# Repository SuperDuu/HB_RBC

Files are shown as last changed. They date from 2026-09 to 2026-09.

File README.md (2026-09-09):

# HB_RBC — H-Bridge DC Motor Driver (Robocon DKH 2026)

**HB_RBC** là mạch điều khiển động cơ DC (Full H-Bridge Driver) công suất cao được thiết kế phục vụ cho đội tuyển **Robocon DKH 2026**. 

Mạch hướng tới sự nhỏ gọn, độ tin cậy cao trong thi đấu thực tế, tích hợp sẵn vi điều khiển trung tâm, mạch lái cổng chống trùng dẫn, cổng phản hồi encoder vòng kín và giao tiếp mạng bus RS-485.

---

## 🚀 Tính năng & Cấu hình chính

- **Vi điều khiển trung tâm**: STM32G030F6Px (ARM Cortex-M0+ @ 64MHz) điều khiển băm xung PWM và xử lý thuật toán vòng kín.
- **Tầng công suất Cầu H**: 
  - 4x N-MOSFET **BSC040N10NS5** ($100\text{V}$, $4.0\text{ m}\Omega$, gói TDSON-8) trở kháng siêu thấp, tỏa nhiệt ít khi chạy tải nặng.
  - Diode xả tự do Schottky (SS310) bảo vệ chống xung ngược cảm ứng từ động cơ.
- **Mạch lái cổng (Gate Driver)**: 
  - 2x IC lái nửa cầu **IR2184** tích hợp sẵn deadtime phần cứng $500\text{ns}$ chống chập nguồn (shoot-through).
  - Tích hợp đường ngắt khẩn cấp phần cứng (`/S`), cho phép khóa cầu H ngay lập tức khi có sự cố.
- **Nguồn cấp**: 
  - Điện áp danh định: $12\text{V} \sim 24\text{V}$ DC (bảo vệ quá dòng qua cầu chì đầu vào).
  - Hạ áp 3 tầng riêng biệt: $24\text{V} \to 15\text{V}$ (Lái Gate) $\to 5\text{V}$ $\to 3.3\text{V}$ (Logic & MCU).
- **Giao tiếp & Cảm biến**:
  - **RS-485 (MAX3485)**: Giao tiếp vi sai chống nhiễu, tích hợp sẵn trở tải $120\Omega$ và mạch phân cực bus.
  - **Encoder AB**: Cổng nhận xung kênh đôi hỗ trợ kiểm soát tốc độ / vị trí động cơ.
  - **Debug SWD**: Header chuẩn nạp chương trình bằng ST-Link.
- **Quy cách PCB**: $50 \times 60\text{ mm}$, 2 lớp đồng, pad hàn dây nguồn và động cơ khổ lớn $4 \times 8\text{ mm}$, 4 lỗ ốc M3.

---

## 🔌 Sơ đồ kết nối ngoại vi

| Cổng | Loại đầu nối | Chức năng | Chi tiết chân |
| :--- | :--- | :--- | :--- |
| **J3 / J4** | Solder Pad $4 \times 8\text{ mm}$ | **Nguồn vào DC** | `J3`: +24V (qua cầu chì) \| `J4`: GND |
| **J1 / J2** | Solder Pad $4 \times 8\times\text{ mm}$ | **Đầu ra Động cơ** | `J1`: M+ \| `J2`: M- |
| **J5** | JST-XH 2.50mm 2P | **Bus RS-485** | Pin 1: B \| Pin 2: A |
| **J6** | JST-XH 2.50mm 4P | **Cảm biến Encoder** | Pin 1: +3.3V \| Pin 2: Kênh A (PA6) \| Pin 3: Kênh B (PA7) \| Pin 4: GND |
| **J7** | JST-XH 2.50mm 4P | **Cổng nạp SWD** | Pin 1: +3.3V \| Pin 2: SWDIO (PA13) \| Pin 3: SWCLK (PA14) \| Pin 4: GND |

---

## 👨‍💻 Thông tin dự án

- **Đơn vị phát triển**: Robocon DKH 2026
- **Thiết kế phần cứng**: Vũ Đức Du ([@SuperDuu](https://github.com/SuperDuu))
- **Công cụ thiết kế**: KiCad EDA

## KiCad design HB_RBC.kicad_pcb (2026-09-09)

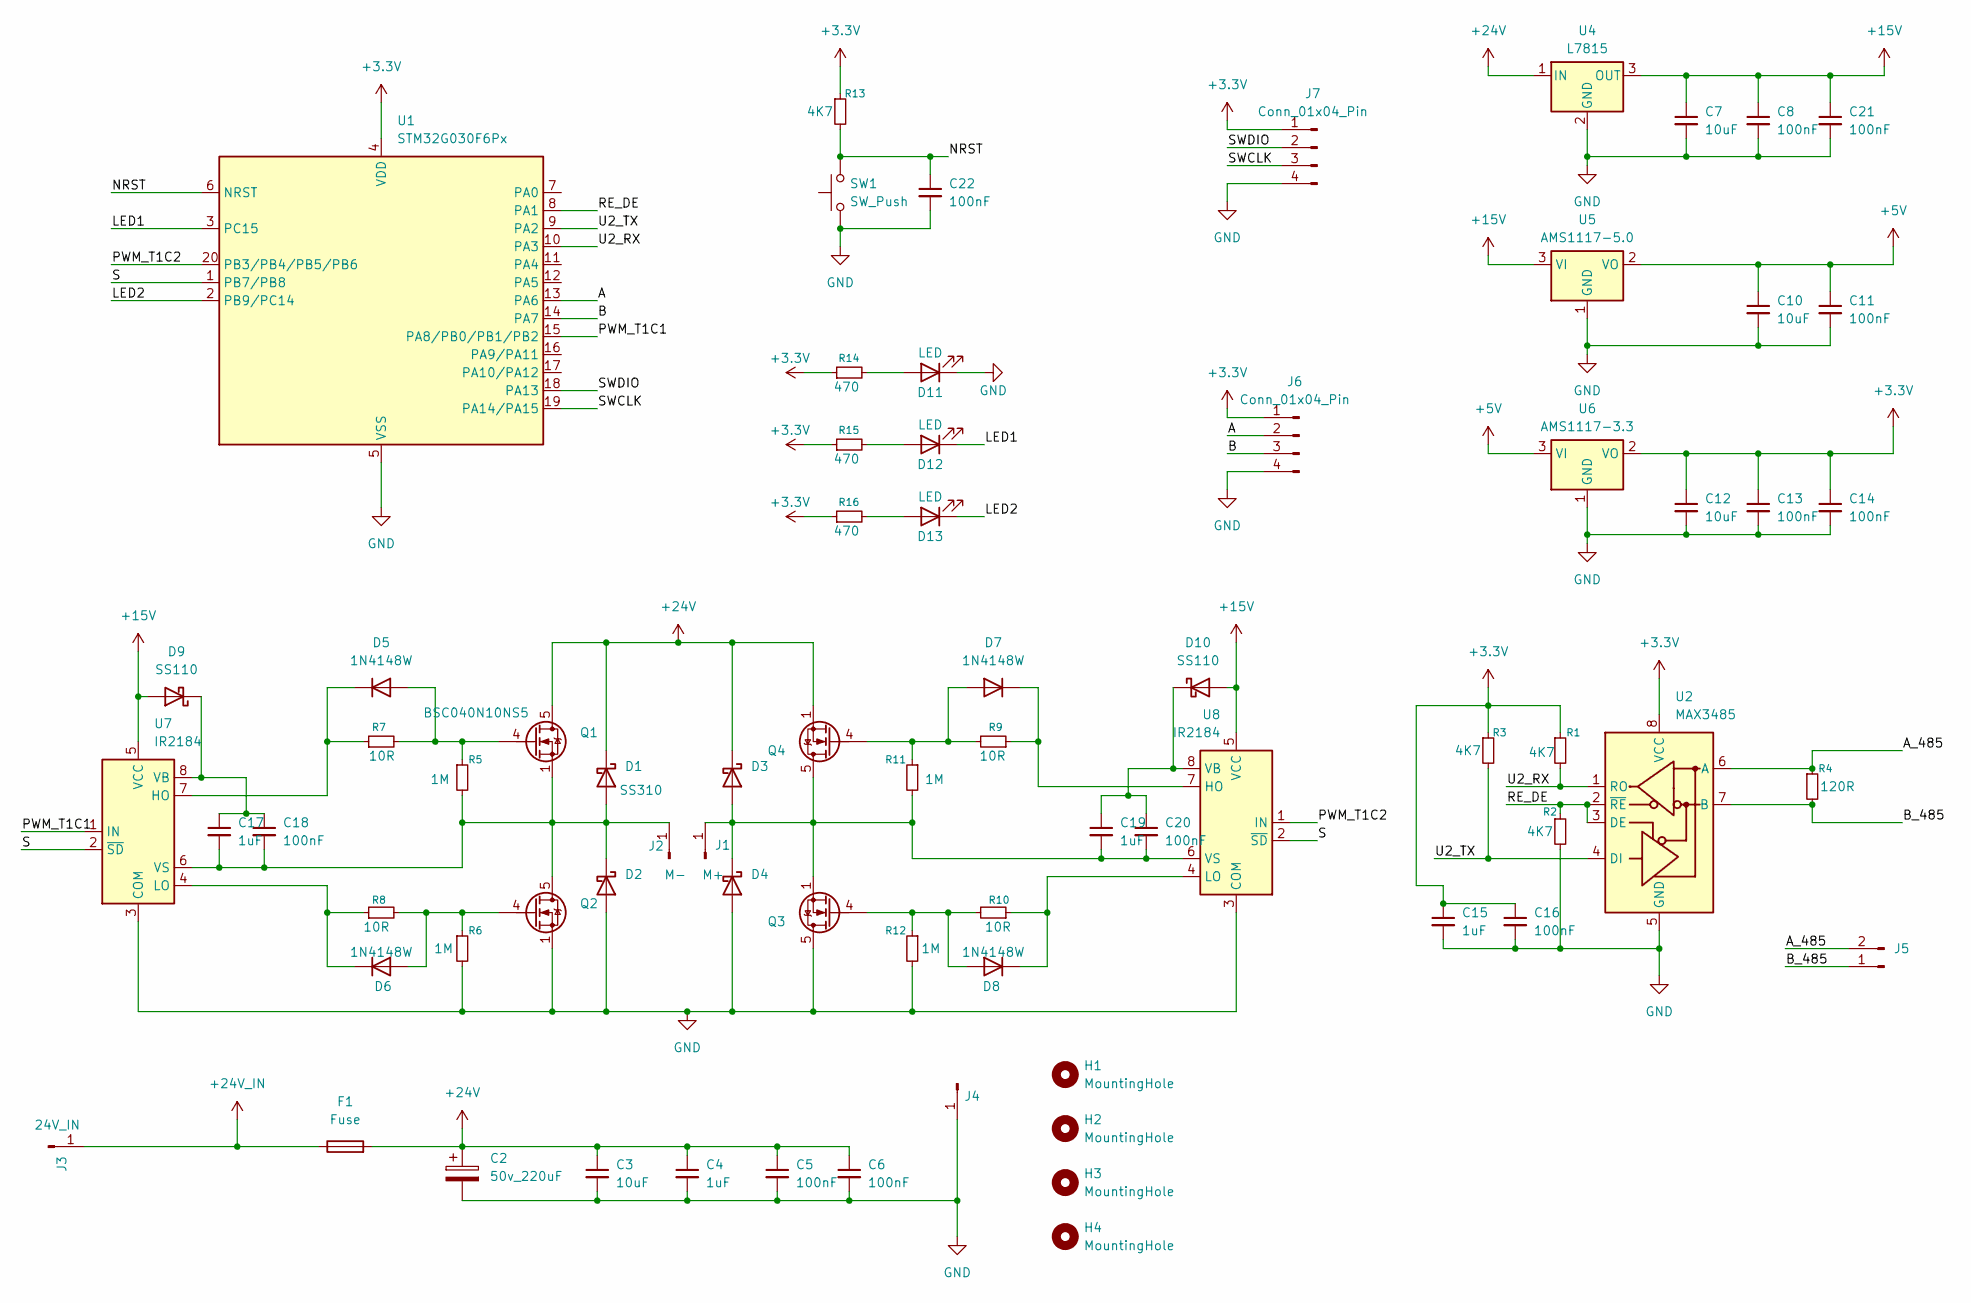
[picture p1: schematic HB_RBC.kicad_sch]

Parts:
C2: 50v_220uF; CP_Elec_10x10.5
C3, C7, C10, C12: 10uF; C_0805_2012Metric_Pad1.18x1.45mm_HandSolder
C4, C15, C17, C19: 1uF; C_0805_2012Metric_Pad1.18x1.45mm_HandSolder
C5, C6, C8, C11, C13, C14, C16, C18, C20, C21, C22: 100nF; C_0805_2012Metric_Pad1.18x1.45mm_HandSolder
D1: SS310; D_SMA
D2, D3, D4: D_Schottky; D_SMA
D5, D6, D7, D8: 1N4148W; D_SOD-123
D9, D10: SS110; D_SMA
D11, D12, D13: LED; LED_0805_2012Metric_Pad1.15x1.40mm_HandSolder
F1: Fuse; Fuseholder_Cylinder-5x20mm_Schurter_0031_8201_Horizontal_Op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
H1, H2, H3, H4: MountingHole; MountingHole_3.2mm_M3_ISO14580_Pad_TopBottom
J1: M+; SolderWirePad_1x01_SMD_4x8mm
J2: M-; SolderWirePad_1x01_SMD_4x8mm
J3: 24V_IN; SolderWirePad_1x01_SMD_4x8mm
J4: Conn_01x01_Pin; SolderWirePad_1x01_SMD_4x8mm
J5: Conn_01x02_Pin; JST_XH_S2B-XH-A-1_1x02_P2.50mm_Horizontal
J6, J7: Conn_01x04_Pin; JST_XH_S4B-XH-A-1_1x04_P2.50mm_Horizontal
Q1, Q2, Q3, Q4: BSC040N10NS5; TDSON-8-1
R1, R2, R3, R13: 4K7; R_0805_2012Metric_Pad1.20x1.40mm_HandSolder
R4: 120R; R_0805_2012Metric_Pad1.20x1.40mm_HandSolder
R5, R6, R11, R12: 1M; R_0805_2012Metric_Pad1.20x1.40mm_HandSolder
R7, R8, R9, R10: 10R; R_0805_2012Metric_Pad1.20x1.40mm_HandSolder
R14, R15, R16: 470; R_0805_2012Metric_Pad1.20x1.40mm_HandSolder
SW1: SW_Push; SW_Tactile_SPST_NO_Straight_CK_PTS636Sx25SMTRLFS
U1: STM32G030F6Px; TSSOP-20_4.4x6.5mm_P0.65mm
U2: MAX3485; SOIC-8_3.9x4.9mm_P1.27mm
U4: L7815; TO-263-3_TabPin2
U5: AMS1117-5.0; SOT-223-3_TabPin2
U6: AMS1117-3.3; SOT-223-3_TabPin2
U7, U8: IR2184; SOIC-8_3.9x4.9mm_P1.27mm

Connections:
+3.3V: C12.1, C13.1, C14.1, C15.1, C16.1, J6.1, J7.1, R1.1, R3.1, R13.1, R14.1, R15.1, R16.1, U1.4 (VDD), U2.8 (VCC), U6.2 (VO)
+5V: C10.1, C11.1, U5.2 (VO), U6.3 (VI)
+15V: C7.1, C8.1, C21.1, D9.2 (A), D10.2 (A), U4.3 (OUT), U5.3 (VI), U7.5 (VCC), U8.5 (VCC)
+24V: C2.1, C3.1, C4.1, C5.1, C6.1, D1.1 (K), D3.1 (K), F1.2, Q1.5 (D), Q4.1 (S), Q4.2 (S), Q4.3 (S), U4.1 (IN)
+24V_IN: F1.1, J3.1 (Pin_1_1)
/A: J6.2, U1.13 (PA6)
/A_485: J5.2, R4.1, U2.6 (A)
/B: J6.3, U1.14 (PA7)
/B_485: J5.1, R4.2, U2.7 (B)
/LED1: D12.1 (K), U1.3 (PC15)
/LED2: D13.1 (K), U1.2 (PB9/PC14)
/NRST: C22.1, R13.2, SW1.2, U1.6 (NRST)
/PWM_T1C1: U1.15 (PA8/PB0/PB1/PB2), U7.1 (IN)
/PWM_T1C2: U1.20 (PB3/PB4/PB5/PB6), U8.1 (IN)
/RE_DE: R2.1, U1.8 (PA1), U2.2 (~RE), U2.3 (DE)
/S: U1.1 (PB7/PB8), U7.2 (~SD), U8.2 (~SD)
/SWCLK: J7.3, U1.19 (PA14/PA15)
/SWDIO: J7.2, U1.18 (PA13)
/U2_RX: R1.2, U1.10 (PA3), U2.1 (RO)
/U2_TX: R3.2, U1.9 (PA2), U2.4 (DI)
GND: C2.2, C3.2, C4.2, C5.2, C6.2, C7.2, C8.2, C10.2, C11.2, C12.2, C13.2, C14.2, C15.2, C16.2, C21.2, C22.2, D2.2 (A), D4.2 (A), D11.1 (K), J4.1 (Pin_1_1), J6.4, J7.4, Q2.1 (S), Q2.2 (S), Q2.3 (S), Q3.5 (D), R2.2, R6.2, R12.2, SW1.1, U1.5 (VSS), U2.5 (GND), U4.2 (GND), U5.1 (GND), U6.1 (GND), U7.3 (COM), U8.3 (COM)
unnamed: C17.2, C18.2, D1.2 (A), D2.1 (K), J2.1 (Pin_1_1), Q1.1 (S), Q1.2 (S), Q1.3 (S), Q2.5 (D), R5.2, U7.6 (VS)
unnamed: C19.2, C20.2, D3.2 (A), D4.1 (K), J1.1 (Pin_1_1), Q3.1 (S), Q3.2 (S), Q3.3 (S), Q4.5 (D), R11.2, U8.6 (VS)
unnamed: D5.2 (A), Q1.4 (G), R5.1, R7.2
unnamed: D5.1 (K), R7.1, U7.7 (HO)
unnamed: D6.2 (A), Q2.4 (G), R6.1, R8.2
unnamed: D6.1 (K), R8.1, U7.4 (LO)
unnamed: D7.2 (A), Q4.4 (G), R9.2, R11.1
unnamed: D7.1 (K), R9.1, U8.7 (HO)
unnamed: D8.2 (A), Q3.4 (G), R10.2, R12.1
unnamed: D8.1 (K), R10.1, U8.4 (LO)
unnamed: C17.1, C18.1, D9.1 (K), U7.8 (VB)
unnamed: C19.1, C20.1, D10.1 (K), U8.8 (VB)
unnamed: D11.2 (A), R14.2
unnamed: D12.2 (A), R15.2
unnamed: D13.2 (A), R16.2

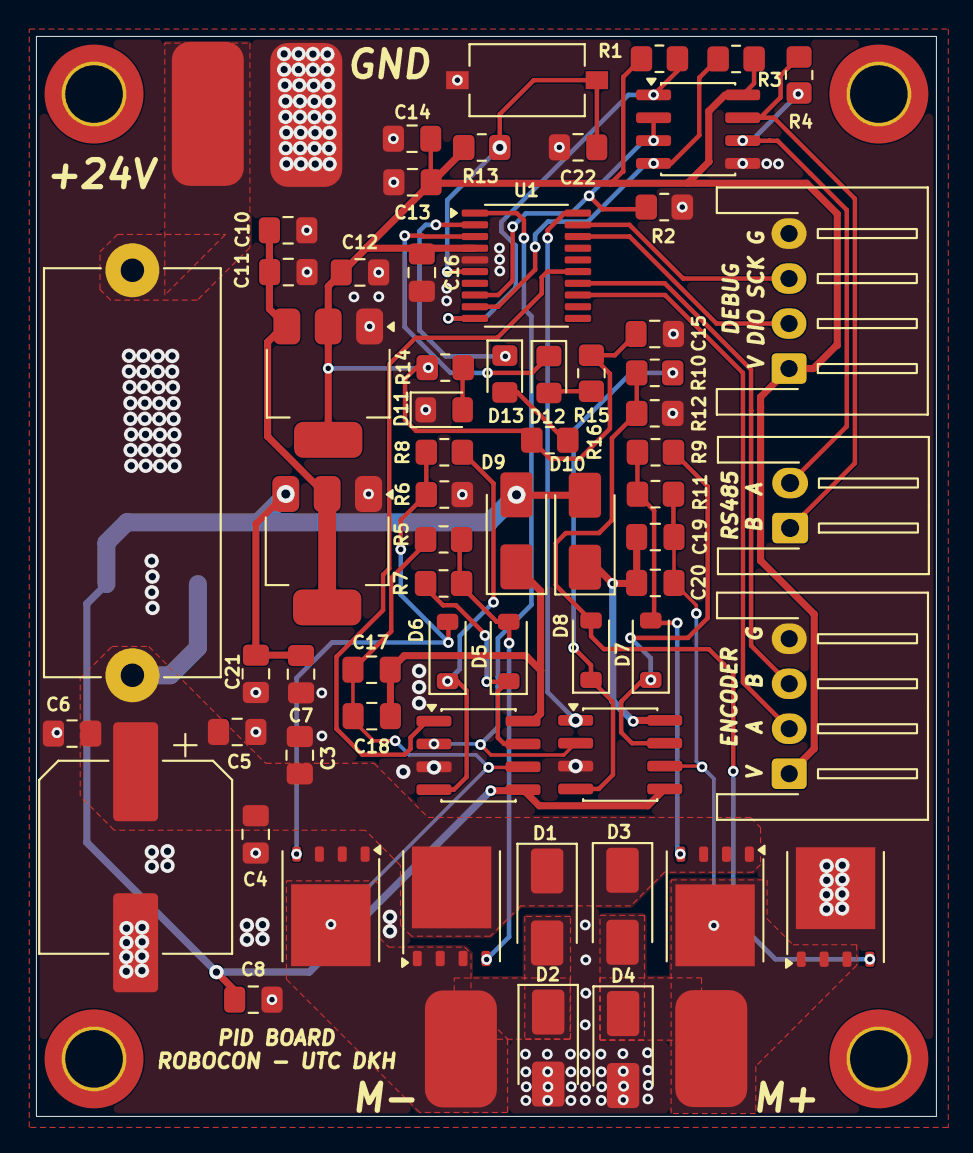
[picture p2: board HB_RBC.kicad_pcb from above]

Board: 2 copper layers, 50.0 x 60.0 mm, 73 parts (1 on the bottom side), 36 nets.

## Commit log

2026-09-09 add kicad project
2026-09-09 add board schematic
    [HB_RBC.kicad_sch]
2026-09-09 add board layout
    [HB_RBC.kicad_pcb]
